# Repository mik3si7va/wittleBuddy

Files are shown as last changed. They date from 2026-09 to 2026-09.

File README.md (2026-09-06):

# Wittle Buddy 🤖

Wittle is a modular 2WD experimental mobile robot built from scratch to learn embedded systems, robotics, sensing, navigation, communications, mapping and autonomous behaviour—with room for a little personality along the way.

The main embedded controller / brain is an **Arduino Mega 2560**, programmed in object-oriented C++ using the Arduino framework and PlatformIO Core. This repository is the starting foundation, and will grow as hardware decisions and experiments become concrete.

## 🎮 First Wireless Drive

On **2026-09-06**, Wittle drove under fully wireless Xbox controller control for the first time. An assembled prototype became a remotely controllable mobile robot. 🤖

**Xbox Controller → Bluetooth → ESP32 → UART → Mega 2560 → Motor Driver → Motors**

### 🎥 [Watch Wittle's first wireless drive](docs/videos/001_mileStone001.mp4)

[**First drive: `001_mileStone001.mp4`**](docs/videos/001_mileStone001.mp4) — the footage lives in this repository; open the link to view or download it.

The **Mega 2560 remains Wittle's brain**: it owns motor control and the final command-timeout failsafe. The ESP32 is the wireless helper, interpreting Bluetooth controller input and sending signed left/right commands over UART. This drive proved the whole chain end-to-end, including both DC motors.

🔋 The wonderfully simple breakthrough for untethered power was a **USB power bank**, keeping the control electronics powered after disconnecting the computer. The motors kept their separate 4.5 V battery pack. This is a temporary prototype solution; see the [power debugging story](#power-debugging-a-small-power-bank-big-moment) and [milestone log](#milestone-log).

The current exp003 source maps the **right analog stick** (`axis_rx` / `axis_ry`), although the milestone description called it the left stick. The documentation follows the checked-in source mapping; see the [ESP32 experiment](experiments/esp32_xbox_controller/README.md#experiment-003-uart-motor-control) and [Mega wiring and failsafes](experiments/motor/README.md).

## Current status

**Body assembled:** the first 2WD chassis is built, with two acrylic decks, two geared DC motors and drive wheels, and two swivel casters. Motor leads have been attached, and the upper deck is in place for mounting electronics. See the [assembly photos](#body-assembly-ass001) below.

**Working on hardware:** Xbox-controlled wireless driving through the ESP32 → UART → Mega → dual motor driver → two DC motors, with portable control power from a USB power bank.

**Implemented:** a PlatformIO Mega firmware target, a lightweight experiment launcher, and a reusable `UltrasonicSensor` class. The active motor experiment (`exp003`) receives signed motor commands from the ESP32 over Serial1 with a 400 ms watchdog. The ultrasonic experiment remains available under `experiments/ultrasonic/`. The five subsystem classes remain skeletons with empty `begin()` and `update()` methods and are not instantiated. There are no automated tests yet.

**Planned:** reusable drive subsystem integration and encoder support, odometry and IMU integration, distance sensing, battery monitoring, communication with higher-level controllers, and a behaviour state machine.

**Experimental / future ideas:** 360-degree LiDAR integration, mapping, autonomous navigation, further ESP32 cooperation and expressive behaviours. These are exploration directions, not working capabilities or settled designs.

## Body assembly (ass001)

Wittle now has an assembled body. Photos 007–011 document the build from the loose chassis parts through motor lead preparation to the assembled base and upper deck.

The two motors and drive wheels are mounted to the lower chassis, with two swivel casters providing support. Standoffs separate the clear acrylic decks, leaving space for electronics. At this assembly stage, controller, motor-driver, sensor and power integration were still ahead. The first powered wireless drive is now recorded above; these photos preserve the earlier assembly milestone.

| Parts laid out | Motor terminal wiring | Motor leads prepared |
| --- | --- | --- |
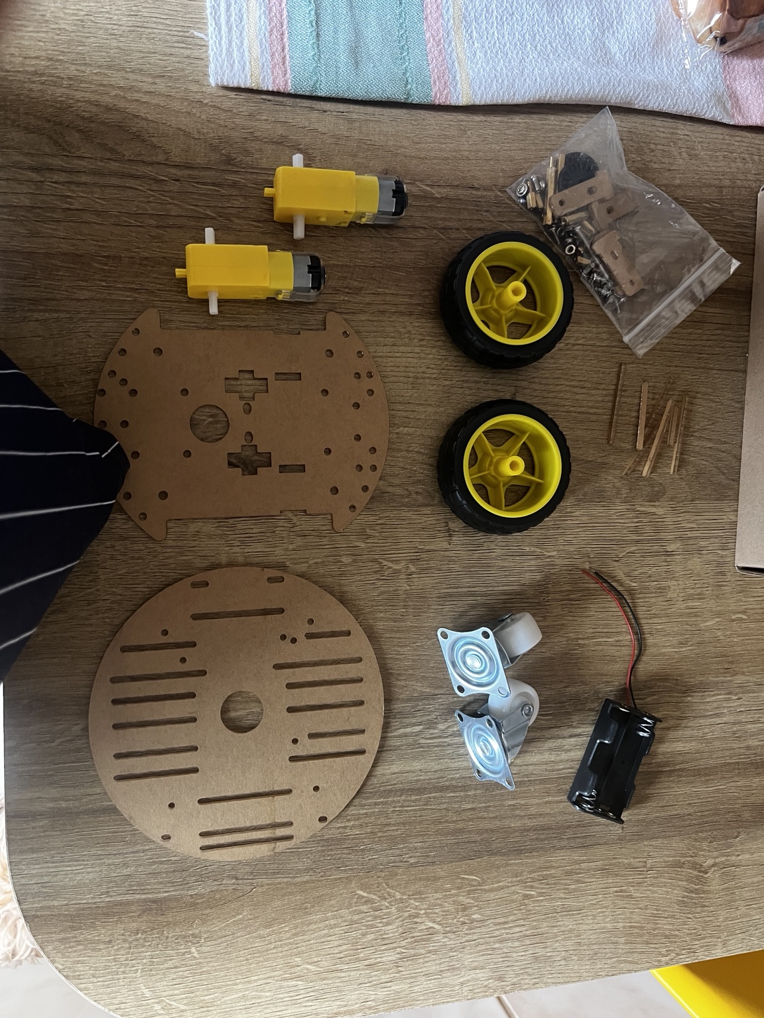
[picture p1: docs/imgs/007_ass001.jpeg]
007: Chassis plates, two motors, wheels, casters and mounting hardware
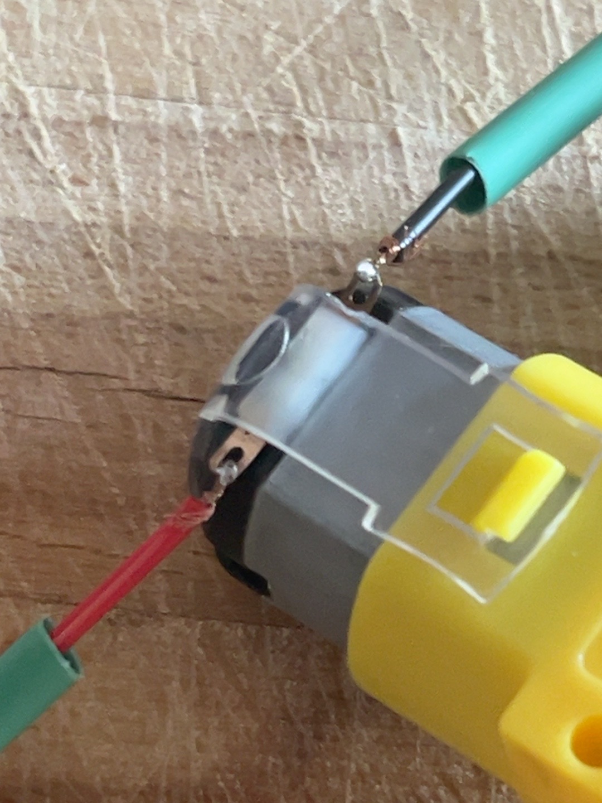
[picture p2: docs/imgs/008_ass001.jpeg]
008: Close-up of motor terminal wiring and insulating sleeves
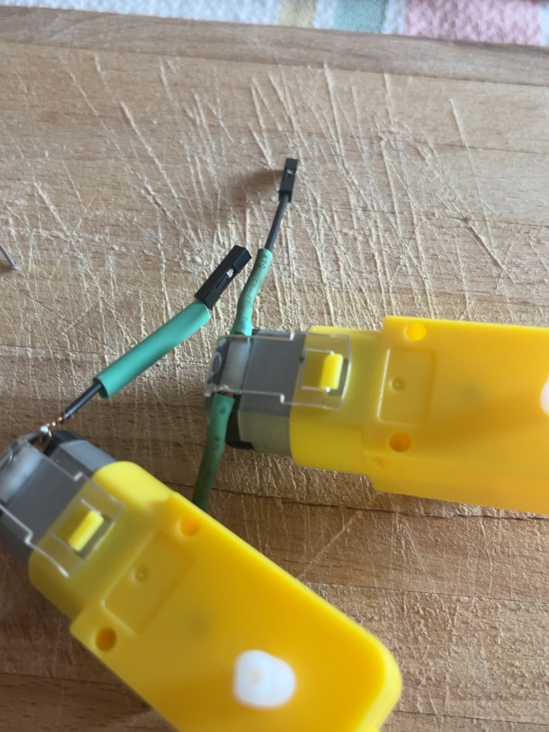
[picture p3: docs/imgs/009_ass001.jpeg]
009: Both geared motors with leads attached
|  |  |  |

| Assembled underside | Upper deck installed |
| --- | --- |
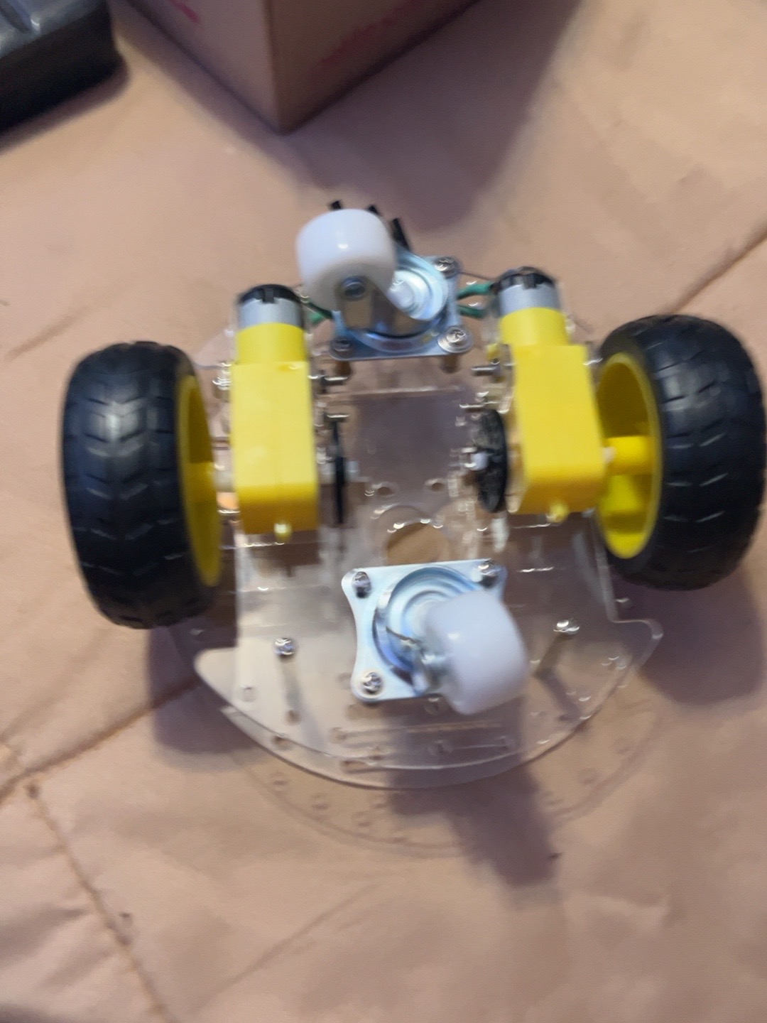
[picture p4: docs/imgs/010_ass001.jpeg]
010: Underside showing the two mounted motors, drive wheels and swivel casters
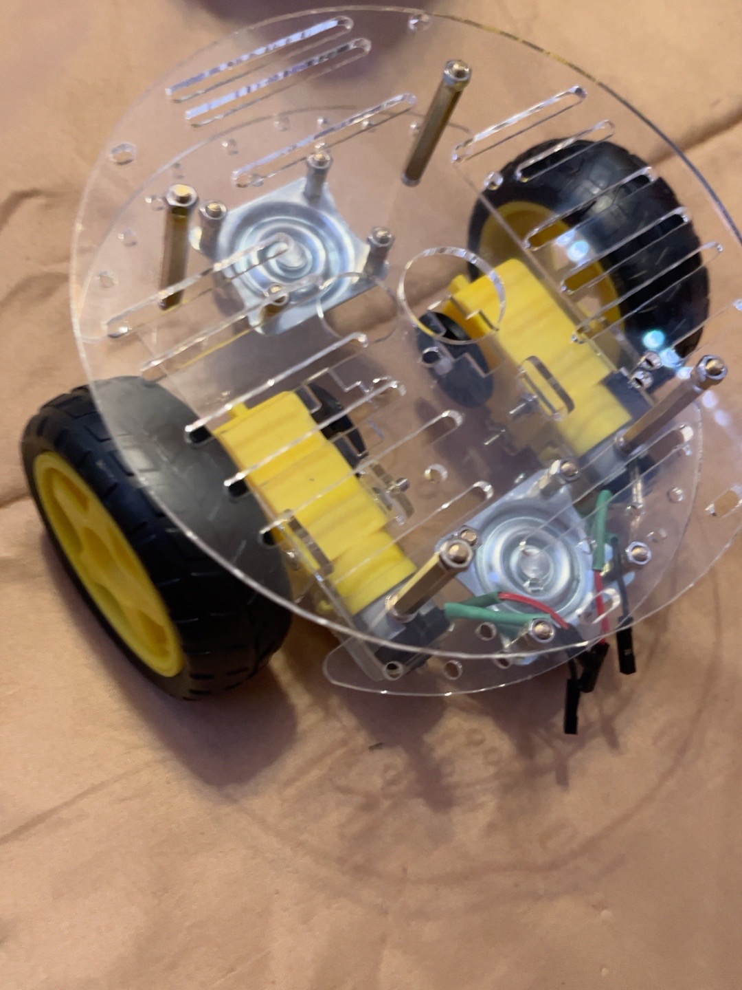
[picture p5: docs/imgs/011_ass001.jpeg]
011: Assembled body with the upper acrylic deck mounted on standoffs
|  |  |

## Architecture

The working exp003 chain is **Xbox controller → Bluetooth → ESP32 → one-way UART → Mega 2560 → GPIO/PWM → dual motor driver → left/right DC motors**. Wireless input belongs to the ESP32; motor actuation and command validation/timeout belong to the Mega. This experiment is working, while the subsystem classes below remain planned integration boundaries.

| System | Planned responsibility |
| --- | --- |
| `DriveSystem` | DC motors and wheel encoders |
| `Navigation` | Odometry, IMU and pose/movement estimation |
| `Perception` | Ultrasonic, ToF and 360-degree LiDAR sensing |
| `PowerSystem` | Battery voltage monitoring and power state |
| `Communication` | Higher-level controllers, telemetry and commands |

`main.cpp` stays small. Future application orchestration and a behaviour state machine will coordinate these systems. The motor and ultrasonic experiments have defined pin assignments; broader robot wiring, protocols and timing contracts remain TBD. See [architecture](docs/architecture.md), [hardware inventory](docs/hardware.md) and [roadmap](docs/roadmap.md).

## Repository structure

```text
wittleBuddy/
├── README.md
├── platformio.ini
├── .vscode/extensions.json       # Optional PlatformIO IDE recommendation
├── docs/
│   ├── architecture.md
│   ├── hardware.md
│   ├── roadmap.md
│   ├── imgs/                     # Assembly and experiment photos
│   └── videos/                   # First wireless drive footage
├── include/                     # UltrasonicSensor.h and subsystem interfaces
├── src/                         # Launcher, UltrasonicSensor.cpp and subsystem skeletons
├── test/                        # Reserved for PlatformIO tests
└── experiments/                 # Implementations; selected experiment is built
    ├── motor/
    ├── esp32_xbox_controller/    # Separate ESP32 PlatformIO project
    ├── encoder/
    ├── ultrasonic/
    ├── tof/
    ├── servo/
    └── lidar/
```

PlatformIO makes `include/` available for headers. The root configuration sets `src_dir = .` and explicitly selects these implementation files with `build_src_filter`:

```ini
build_src_filter =
    +<src/main.cpp>
    +<experiments/motor/exp003.cpp>
```

This compiles the experiment in place, without copying it into `src/` or creating another project or environment. Other experiments and the subsystem skeletons are not compiled.

## Running experiments

`src/main.cpp` owns the Arduino `setup()` and `loop()` functions. It includes the experiment header and delegates to `motorExperimentSetup()` and `motorExperimentLoop()`. The implementation stays in `experiments/motor/exp003.cpp`.

The experiment starts both motors stopped, then receives `left,right` commands over Serial1 at 115200 baud. Positive commands use IN1 LOW / IN2 HIGH; a 400 ms command timeout stops both motors. See the [motor experiment README](experiments/motor/README.md) for wiring and bench-test instructions.

To activate a future experiment, keep its implementation and header under its own `experiments/` directory, update the header and calls in `src/main.cpp`, and replace the experiment path in `build_src_filter`. Explicitly include any reusable implementation files it needs. Keep Arduino entry points in `main.cpp`; no selector or registry is required.

## Development setup

Use Python 3 and [PlatformIO Core](https://docs.platformio.org/en/latest/core/installation/). A user-local installation keeps Python packages separate from Fedora's system Python:

```sh
python3 -m venv "$HOME/.platformio/penv"
"$HOME/.platformio/penv/bin/python" -m pip install platformio
export PATH="$HOME/.platformio/penv/bin:$PATH"
pio --version
```

On the initial development machine, Core is installed at that location, with `pio` and `platformio` links in `~/.local/bin` already on PATH. No system package or permission changes were needed. If another machine lacks Python or venv support, resolve its prerequisites before proceeding; do not run PlatformIO with sudo.

For VS Code, open this repository and optionally install the recommended **PlatformIO IDE** extension (`platformio.platformio-ide`). The CLI works independently in VS Code's terminal. Generated PlatformIO build and editor files are ignored by Git.

The board configuration follows the [PlatformIO Mega 2560 definition](https://docs.platformio.org/en/stable/boards/atmelavr/megaatmega2560.html). The Atmel AVR platform is pinned to version 5.3.0. PlatformIO downloads the compiler and Arduino framework on the first build; the uploader is fetched when needed. These downloads require internet access.

## Build, detect, upload and monitor

Run from the repository root:

```sh
pio run -e mega2560
pio device list
```

On the initial machine, USB ID `2341:0042` identifies the Mega 2560 R3 at `/dev/ttyACM0`. Device names can change after reconnecting; check the list before using the following commands.

**Upload only when you choose to replace the board's current firmware:**

```sh
pio run -e mega2560 -t upload --upload-port /dev/ttyACM0
```

For firmware that uses Serial, monitor output with:

```sh
pio device monitor -e mega2560 --port /dev/ttyACM0 --baud 115200
```

Exit the monitor with Ctrl+C and close it before uploading. The current motor experiment prints received commands and failsafe events over USB Serial at 115200; motor commands arrive separately on Serial1 RX pin 19. The startup message in the historical validation record below belongs to the earlier minimal firmware.

For serial access, inspect `id` and `ls -l /dev/ttyACM0`. On the initial Fedora machine the user is already in `dialout`, and the device is read/write for that group. No extra udev rules were needed for this connected board. Review any future permission change explicitly rather than granting world-writable access.

## Sensor refactor build validation (historical)

The sensor-class refactor passed `pio run -e mega2560`: flash usage was 2,348 / 253,952 bytes and RAM usage was 21 / 8,192 bytes. This verified compilation and linking; no firmware upload was performed during the refactor.

## Initial validation (historical)

On 2026-09-05, `pio run -e mega2560` succeeded on Fedora 44 with PlatformIO Core 6.1.19, Atmel AVR 5.3.0, AVR GCC 7.3.0 and Arduino AVR framework package 5.4.0. Flash usage was 1,856 / 253,952 bytes; RAM usage was 188 / 8,192 bytes. AVRDUDE 6.3 was installed separately through PlatformIO and its help command ran successfully. PlatformIO device enumeration and the monitor CLI were available.

The connected Arduino Mega 2560 at `/dev/ttyACM0` was successfully flashed using AVRDUDE. All 1,856 bytes were written and verified. After reset, serial communication at 115200 baud was verified with the exact startup output:

```text
Wittle Buddy starting up!
```

The received bytes were `b'Wittle Buddy starting up!\r\n'`. This confirms the minimal firmware runs and serial communication works; robot subsystems remain unimplemented. Serial access permissions were checked, and no system packages, group memberships or udev rules were changed.

## Power debugging: a small power bank, big moment

The ESP32 initially ran from the Mega's 5 V rail while the Mega was connected to USB. Removing the computer tether exposed a power problem:

| Attempt | What happened / lesson |
| --- | --- |
| Small rectangular 9 V battery → Mega external input → onboard regulator → Mega 5 V rail → ESP32 | The ESP32/controller setup became unreliable. The likely bottleneck was the small battery plus the Mega regulator supplying the combined Mega + ESP32 wireless load. |
| Motor battery pack (4.5 V) → ESP32 VIN/5V input | Also unsatisfactory. 4.5 V is marginal at the development board's VIN/5V input, and directly sharing motor power introduces voltage-drop and motor-noise concerns. |
| USB power bank → control electronics | Worked: portable regulated USB power kept the Mega/ESP32 system running with the computer disconnected. Motors retained their separate 4.5 V supply through driver VM, with common ground. |

After experimenting with a 9 V battery and the motor supply, the breakthrough power solution for the first untethered test was unexpectedly simple: **a USB power bank**. Sometimes the next robotics breakthrough is already in a drawer. 🔋

The unsuccessful arrangements were abandoned. These observations point to the power architecture; they are not measured regulator or noise diagnoses. The power bank is a **temporary prototype solution**, not a settled final design. A future main rechargeable battery with appropriate DC-DC regulation can supply the robot; that architecture has not been implemented.

## Milestone log

### 2026-09-06 — First wireless drive 🎮📡

1. Soldered the motor-driver header pins, brought the board online and debugged its wiring. Missing **VM motor power** explained why the motors initially would not move.
2. Successfully tested both DC motors. Both initially ran backwards; software direction was corrected and forward was experimentally confirmed as **AIN1/BIN1 LOW, AIN2/BIN2 HIGH**.
3. Connected the Xbox controller to the ESP32 over Bluetooth, implemented/tested ESP32 → Mega UART, and had the Mega translate wireless commands into motor movement.
4. Tried removing the USB tether with a small 9 V battery through the Mega and then the existing 4.5 V motor supply for the ESP32. Neither arrangement reliably powered the wireless setup.
5. Used a USB power bank as temporary portable 5 V control power, keeping the motors on their separate battery supply. Wittle completed its **first fully wireless Xbox-controlled drive**.
6. Recorded the first-drive footage, present here as [001_mileStone001.mp4](docs/videos/001_mileStone001.mp4) (called `Wittle001.mp4` in the session description).

This was the day Wittle moved beyond an assembled prototype and became a remotely controllable mobile robot. Hardware results above are from the reported driving session; implemented failsafes are documented separately from suggested bench checks.

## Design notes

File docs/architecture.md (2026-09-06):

# Software architecture

## Current implementation

The project uses PlatformIO's Arduino framework for the Mega 2560. `src/main.cpp` owns Arduino `setup()` and `loop()` and delegates to the active motor experiment through `experiments/motor/exp003.h`.

The working control chain, proven in the first wireless drive on **2026-09-06**, is Xbox controller → Bluetooth → ESP32 → UART → Mega 2560 → GPIO/PWM → dual motor driver → two DC motors. The **Mega is the main controller / brain** and owns motor control, packet validation and the 400 ms command timeout. The ESP32 is the wireless helper: its separate ESP-IDF/Bluepad32 project mixes right-stick input and sends `left,right\n` commands at 115200 baud every 50 ms. Its 300 ms input timeout is checked on the next timer tick. See the [Mega experiment](../experiments/motor/README.md) and [ESP32 experiment](../experiments/esp32_xbox_controller/README.md#experiment-003-uart-motor-control).

The earlier ultrasonic experiment remains available. It owns three `UltrasonicSensor` objects, compares their distances, and controls traffic-light LEDs. `UltrasonicSensor` stores one TRIG/ECHO pin pair and provides `begin()` and `measureDistance()`; it has no LED or navigation responsibilities. Each subsystem has a header in `include/` and a source in `src/`; `begin()` and `update()` are empty placeholders. No subsystem is instantiated or included in the current build filter.

## Planned boundaries

| Class | Responsibility | Decisions still required |
| --- | --- | --- |
| DriveSystem | Motor actuation and encoder acquisition | Integrate tested motor wiring; encoder format, command and feedback interfaces |
| Navigation | Odometry, IMU integration, pose/movement estimation | IMU, calibration, coordinate frames and data contracts |
| Perception | Ultrasonic, ToF and 360-degree LiDAR sensing | Models, interfaces, sampling and validity representation |
| PowerSystem | Battery voltage and power state | Battery, measurement circuit, thresholds and units |
| Communication | Higher-level controller links, telemetry and commands | Integrate tested ESP32 UART link; broader telemetry and message contracts |

The small lifecycle interface is provisional. Add configuration, results and error reporting only as requirements become known. Empty methods do not indicate functioning or successfully initialized hardware.

## Future orchestration

Keep Arduino `setup()` and `loop()` focused on application orchestration. A future behaviour state machine will select modes and coordinate subsystems through explicit interfaces. States, transitions, command ownership and fault responses are TBD; none are implemented.

Prefer bounded, non-blocking updates as functionality is added. Navigation is expected to consume drive feedback, and behaviours to consume navigation, perception and power information; exact dependencies and scheduling are TBD. Keep sensor/driver details behind the subsystem boundaries and avoid shared mutable globals between systems.

Plan memory use and update timing within the Mega's resource limits. Higher-level processing may eventually move to another controller, but no allocation of mapping or autonomy work is decided.

## Experiments and validation

`experiments/` holds investigations compiled in place when explicitly selected. The root `platformio.ini` uses `src_dir = .` and `build_src_filter` to include only `src/main.cpp` and `experiments/motor/exp003.cpp`. Switching experiments means updating the launcher header/calls and the source filter within the same Mega environment.

Record wiring and reproducible observations in the experiment README. `test/` is reserved for meaningful tests as contracts are defined. The earlier sensor refactor passed compilation and linking without uploading; its experiment uses sensor readings and LED responses with no serial output. See the [ultrasonic experiment](../experiments/ultrasonic/README.md). The active motor experiment prints USB Serial diagnostics and was used in the reported first wireless drive. That result is distinct from exhaustive fault-case validation; suggested bench checks remain in the motor README.

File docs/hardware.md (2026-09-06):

# Hardware inventory

Wittle's intended form is a modular two-wheel-drive robot. The chassis is assembled and the first wireless Xbox-controlled drive succeeded on 2026-09-06. The initial controller choice, USB enumeration, firmware upload and serial startup output have also been confirmed here. Inventory entries below do not imply that components are installed or supported in firmware.

| Item | Status / quantity | Model / specification | Connection / pins | Notes |
| --- | --- | --- | --- | --- |
| Primary controller | Confirmed, 1 detected | Arduino Mega 2560 R3 | USB debug; Serial1 RX19; motor pins below | Initial Arduino framework target |
| USB connection | Upload and serial output verified | USB ID 2341:0042 | `/dev/ttyACM0` during validation | AVRDUDE wrote and verified 1,856 bytes; startup message received at 115200 baud after reset |
| Chassis / wheels | Assembled 2WD | Two acrylic decks, drive wheels and two swivel casters | Two geared motors on lower chassis | Dimensions and wheel geometry TBD |
| DC motors | Both tested, 2 | Geared DC motors; ratings/gearing TBD | Left: AO1/AO2; right: BO1/BO2 | Forward orientation confirmed experimentally |
| Motor driver | Dual driver tested | Exact model not recorded here | PWMA=5, AIN1=22, AIN2=23, STBY=24, BIN1=25, BIN2=26, PWMB=6 | VCC=Mega 5 V; VM=separate 4.5 V pack; common GND |
| Wheel encoders | Planned, quantity TBD | TBD | TBD | Resolution and electrical interface TBD |
| IMU | Planned | TBD | TBD | Calibration and mounting TBD |
| Ultrasonic sensors | Planned, quantity TBD | TBD | TBD | Placement TBD |
| ToF sensors | Planned, quantity TBD | TBD | TBD | Placement TBD |
| 360-degree LiDAR | Future exploration | TBD | TBD | Power and processing needs TBD |
| Motor battery | Tested | 4.5 V pack, 3 × 1.5 V cells | Positive to VM; negative to common GND | Chemistry/capacity not recorded; final rechargeable system planned |
| Voltage measurement | Planned | TBD | TBD | Circuit and scaling TBD |
| Control power | Temporary prototype, tested | USB power bank | Portable USB power for Mega/ESP32 controls | Final DC-DC regulation, protection and current budget TBD |
| Wireless helper | Tested with Xbox over Bluetooth | ESP32 project targets ESP32-WROOM / DOIT ESP32 DEVKIT V1 | GPIO17 UART2 TX → Mega RX1 pin 19; common GND; 115200 baud | Mega remains main controller; one-way motor-command link |
| Servo | Experiment placeholder only | TBD | TBD | No robot role assigned |

## Assignment policy

Confirmed motor wiring and software orientation are recorded in the [motor experiment](../experiments/motor/README.md): forward is AIN1/BIN1 LOW and AIN2/BIN2 HIGH. The earlier [ultrasonic experiment](../experiments/ultrasonic/README.md) has its own conflicting pin assignments; disconnect that wiring before using exp003. Broader robot wiring and sensor addresses remain open. Subsystem classes remain empty, while experiment motor and ultrasonic code performs real operations.

The small 9 V battery through the Mega regulator and the shared 4.5 V motor-supply attempt did not reliably power the ESP32/controller setup. Both were abandoned in favour of temporary USB power-bank control power. See the [power debugging story](../README.md#power-debugging-a-small-power-bank-big-moment); a final rechargeable battery/DC-DC architecture is still future work.

## Development host observation

Initial inspection: Fedora Linux 44, user already in `dialout`; `/dev/ttyACM0` is owned by `root:dialout` with mode `0660`, and the current user has read/write access. No permissions or udev rules were changed. Device paths and access must be rechecked on another host or after reconnecting.

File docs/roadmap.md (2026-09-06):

# Roadmap

This is a sequence of learning milestones, not a delivery schedule. Hardware and interface choices remain open.

## Foundation — implemented

- PlatformIO configuration for Mega 2560 and Arduino.
- Minimal serial startup firmware.
- Five subsystem class skeletons, documentation and experiment directories.

## Toolchain bring-up — validation

- Completed: firmware compiles on Fedora; memory usage and tool versions are recorded in the README.
- Completed: Mega detected at `/dev/ttyACM0`; current user has read/write access.
- Completed: AVRDUDE uploaded and verified all 1,856 bytes on the Mega at `/dev/ttyACM0`; after reset, `Wittle Buddy starting up!` was received at 115200 baud.

## First wireless drive — completed, 2026-09-06

- Soldered and debugged motor-driver wiring, identified missing VM power, tested both motors and corrected forward direction in software.
- Proved Xbox → Bluetooth → ESP32 → UART → Mega → motor driver → motors end-to-end.
- Replaced inadequate prototype power attempts with temporary USB power-bank control power and a separate 4.5 V motor pack.
- Recorded [the first wireless drive](videos/001_mileStone001.mp4). See the [full milestone log](../README.md#milestone-log).

## Hardware decisions and isolated experiments — ongoing

- Inventory available components and confirm motor, driver and power requirements.
- Extend confirmed motor/UART and earlier ultrasonic pin assignments as further electrical and timing requirements are checked.
- Investigate motors, encoders, ultrasonic, ToF, servo and LiDAR independently where relevant.
- Record measurements and findings before integrating code.

## Subsystem integration — planned

- Integrate working experiment motor control into DriveSystem and add encoder feedback, followed by odometry and IMU integration.
- Add perception and power monitoring using confirmed hardware.
- Integrate the working ESP32 UART controller link into subsystem communication contracts.
- Develop the final rechargeable battery and appropriate DC-DC regulation beyond temporary power-bank control power.
- Add tests for established logic and repeatable hardware checks for drivers.

## Behaviour coordination — planned

- Define a behaviour state machine, transitions, fault handling and update timing.
- Integrate subsystems incrementally with measurable acceptance criteria.

## Exploration — future ideas

Mapping, autonomous navigation, 360-degree LiDAR processing, further ESP32 cooperation and expressive behaviour remain future investigations. Feasibility and division of work between controllers need experimental evidence.

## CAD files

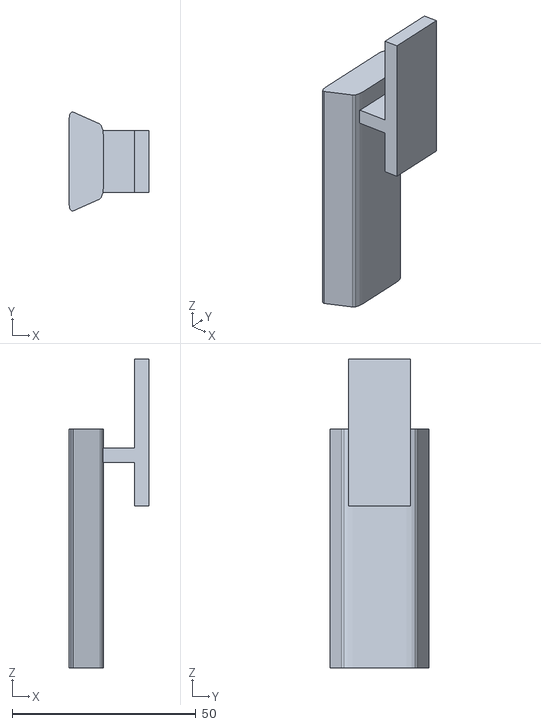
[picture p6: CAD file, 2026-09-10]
blender/stl/v001 (plain)/005_clip.stl
21.7 x 26.9 x 84.1

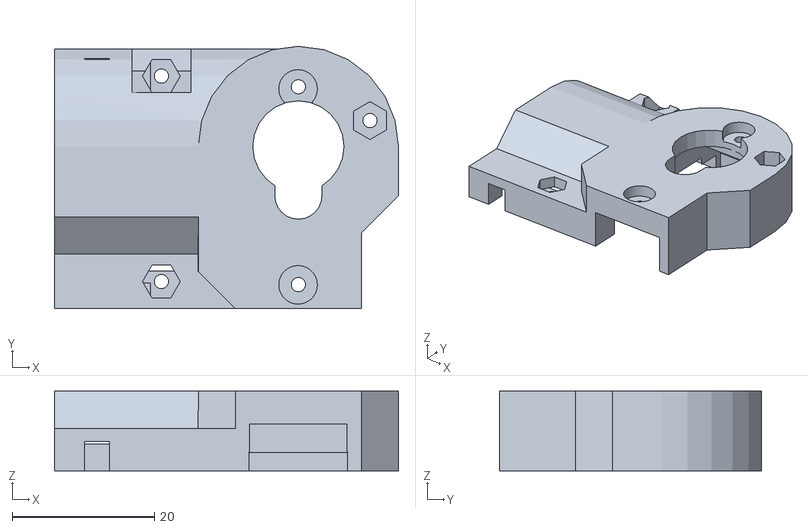
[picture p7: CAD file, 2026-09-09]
blender/stl/v002 (camara)/001_raspicam_pan_tilt_for_mg90s_servos_from_cults3d/PanTilt_Body-A.stl
48.3 x 36.8 x 11.2

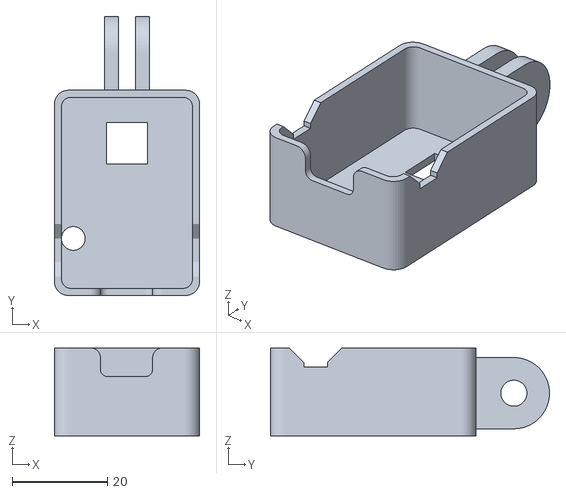
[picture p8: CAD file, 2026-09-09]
blender/stl/v002 (camara)/002_esp32_cam_holder_from_cults3d/ESP32-CAM-Front-Gopro-MB.stl
30.6 x 58.7 x 18.5

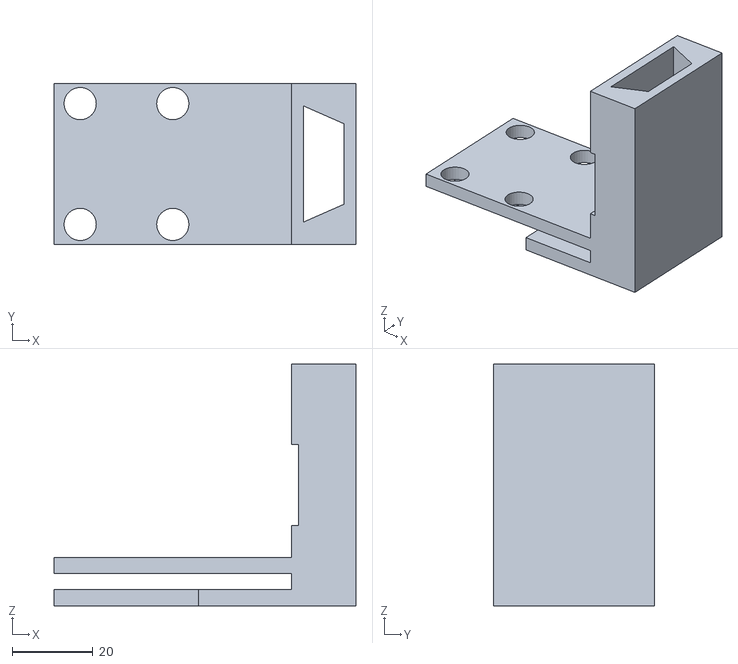
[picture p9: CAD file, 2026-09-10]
blender/stl/v001 (plain)/004_Bp_clamp.stl
75.0 x 40.0 x 60.0

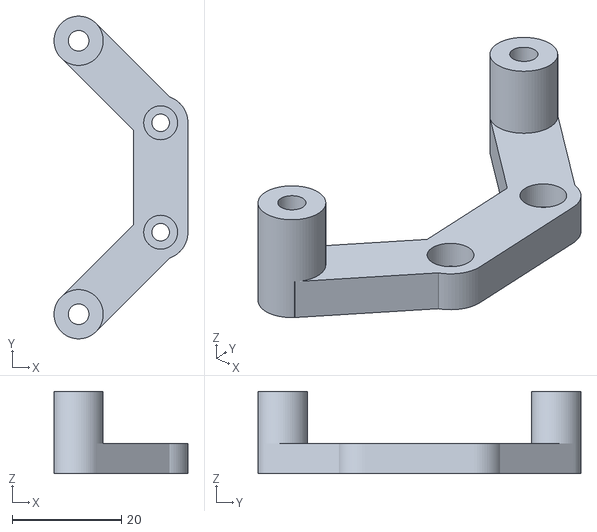
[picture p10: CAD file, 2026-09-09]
blender/stl/v002 (camara)/001_raspicam_pan_tilt_for_mg90s_servos_from_cults3d/PanTilt_Feet_print_x2.stl
24.5 x 59.0 x 15.0

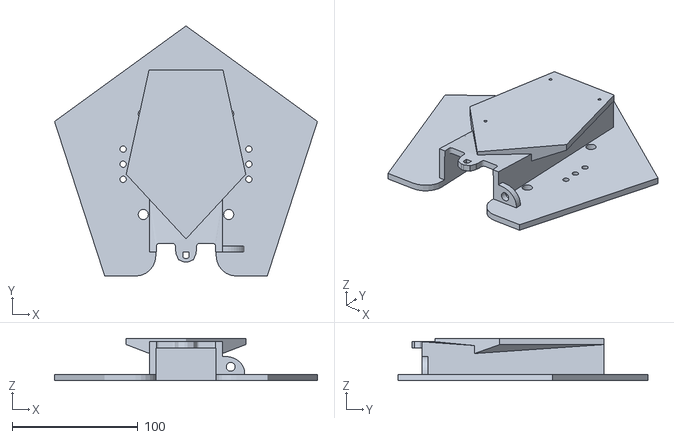
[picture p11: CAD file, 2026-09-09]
blender/stl/v001 (plain)/001_body_v1.stl
209.2 x 199.0 x 33.8

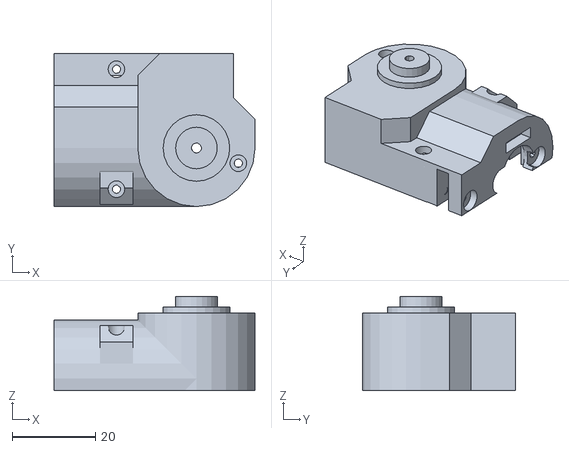
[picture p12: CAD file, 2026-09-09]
blender/stl/v002 (camara)/001_raspicam_pan_tilt_for_mg90s_servos_from_cults3d/PanTilt_Body-B.stl
48.3 x 36.8 x 22.6

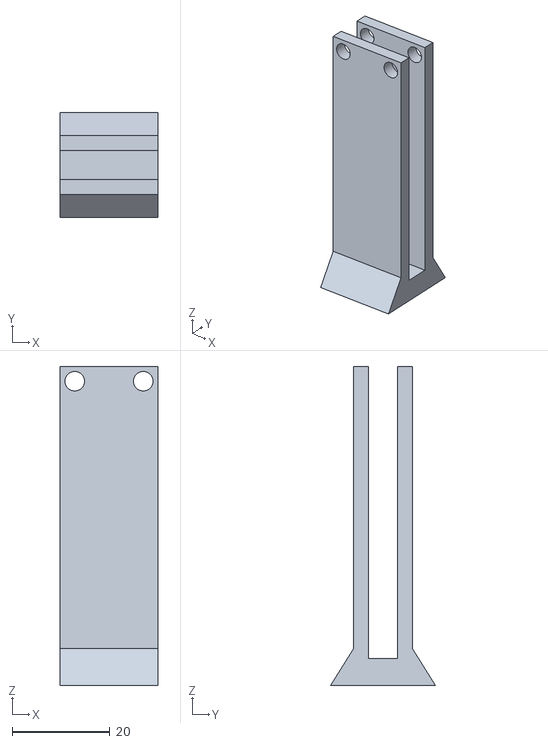
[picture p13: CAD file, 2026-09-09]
blender/stl/v001 (plain)/006_esp_stand.stl
20.0 x 21.5 x 65.2

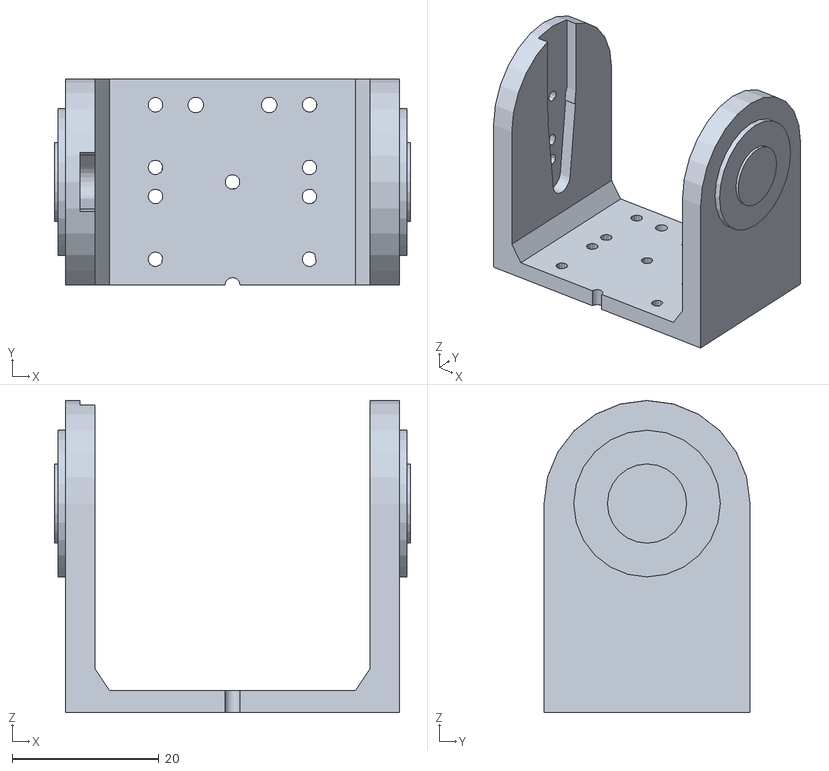
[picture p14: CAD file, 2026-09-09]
blender/stl/v002 (camara)/001_raspicam_pan_tilt_for_mg90s_servos_from_cults3d/PanTilt_Arm.stl
48.5 x 28.1 x 42.5

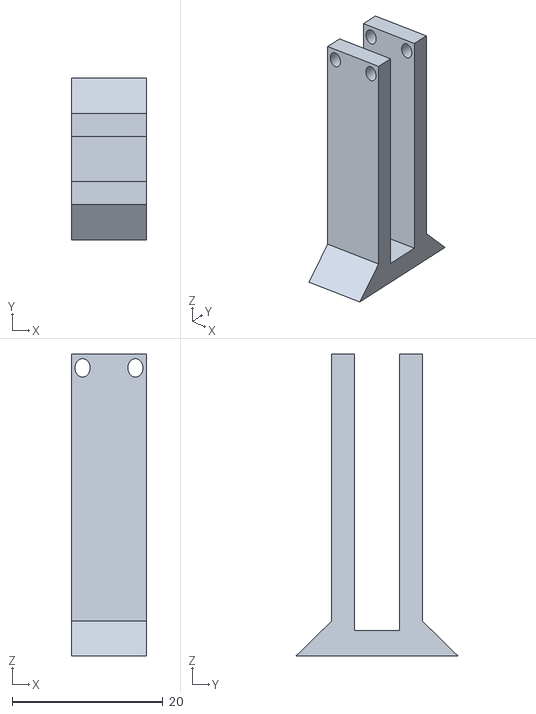
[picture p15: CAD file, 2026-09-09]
blender/stl/v001 (plain)/007_m_driver_stand.stl
10.0 x 21.5 x 40.0

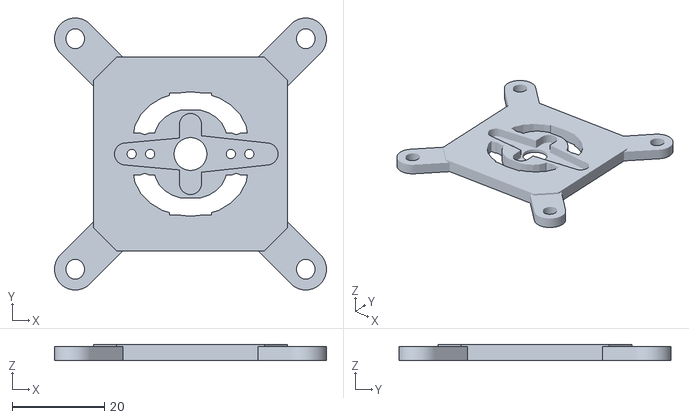
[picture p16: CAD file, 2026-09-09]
blender/stl/v002 (camara)/001_raspicam_pan_tilt_for_mg90s_servos_from_cults3d/PanTilt_Base.stl
59.0 x 59.0 x 3.50

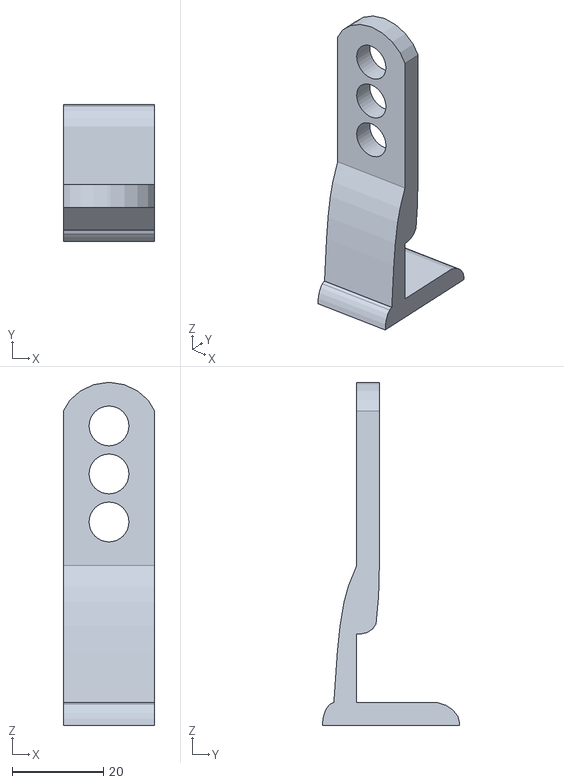
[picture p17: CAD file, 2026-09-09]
blender/stl/v001 (plain)/008_traffic_light_holder.stl
20.0 x 30.0 x 75.0

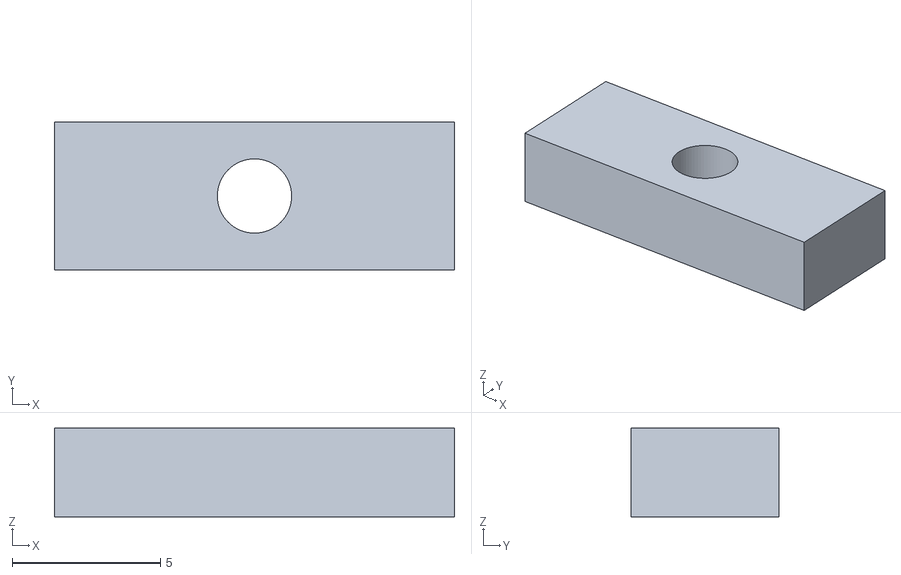
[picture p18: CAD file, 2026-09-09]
blender/stl/v002 (camara)/001_raspicam_pan_tilt_for_mg90s_servos_from_cults3d/PanTilt_Block.stl
13.5 x 5.00 x 3.00

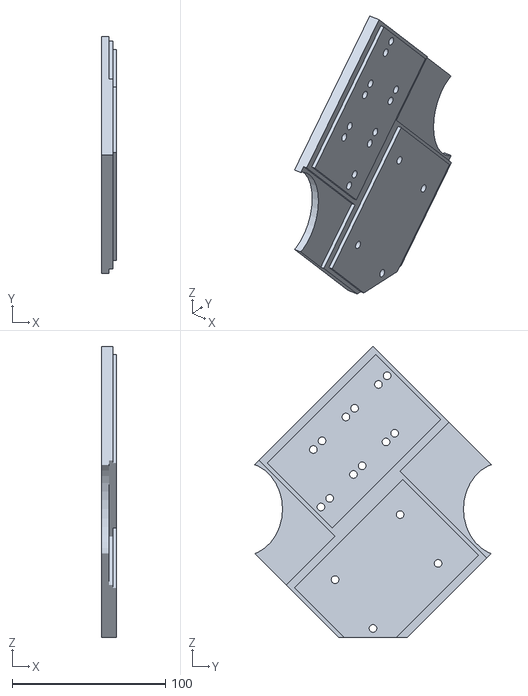
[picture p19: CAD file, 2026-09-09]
blender/stl/v001 (plain)/003_backPlate_v01.stl
10.0 x 154.3 x 189.7

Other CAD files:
blender/stl/v002 (camara)/001_raspicam_pan_tilt_for_mg90s_servos_from_cults3d/PanTilt_Baselock.stl
blender/stl/v001 (plain)/002_body_key_v01.stl
blender/blend/v001/back_plate_v1.blend
blender/blend/v001/body_v1.blend
blender/blend/v001/esp_plus_driver_stand_v1.blend
blender/blend/v001/traffic_light_v1.blend

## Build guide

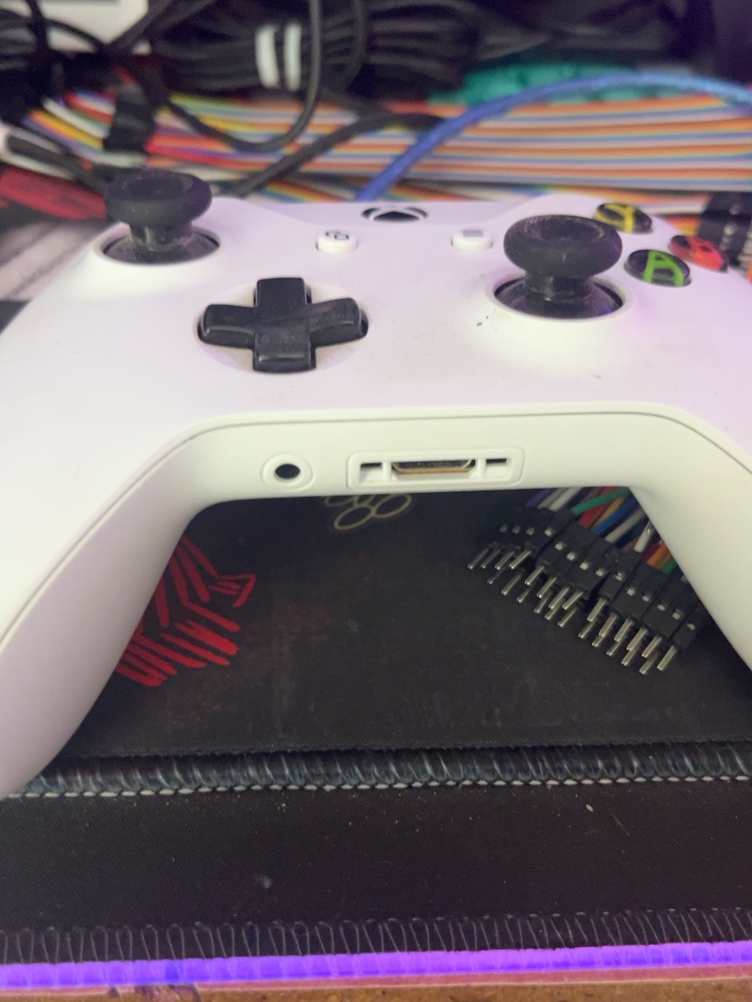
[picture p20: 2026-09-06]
docs/imgs/001_baby_steps/018_exp003.jpeg

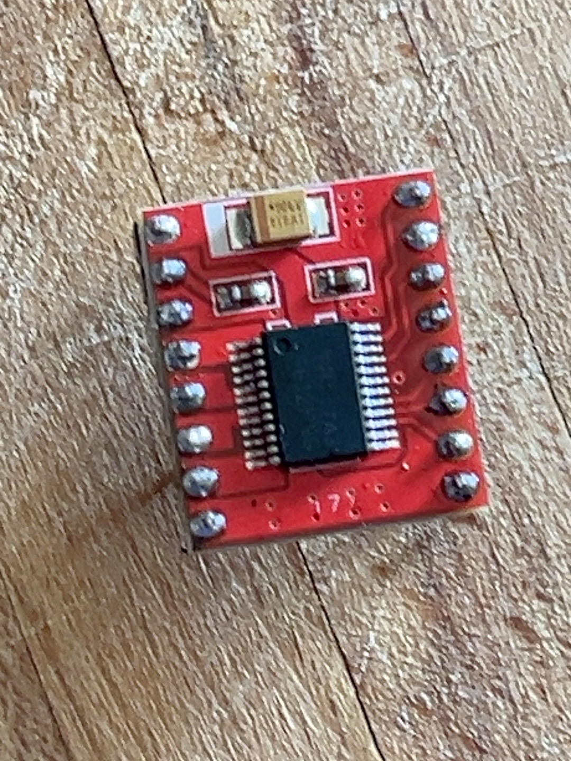
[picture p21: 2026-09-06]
docs/imgs/001_baby_steps/015_exp003.jpeg

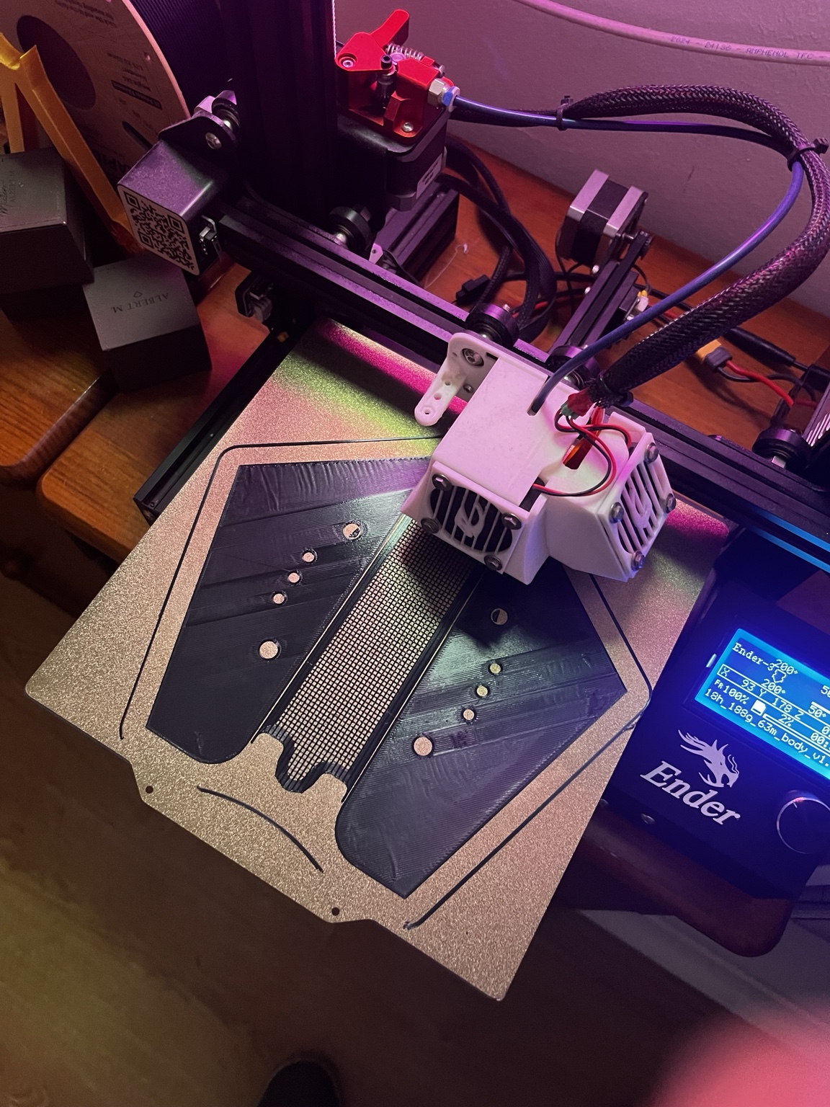
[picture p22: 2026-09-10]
docs/imgs/002_first_prototype/008_printing.jpeg

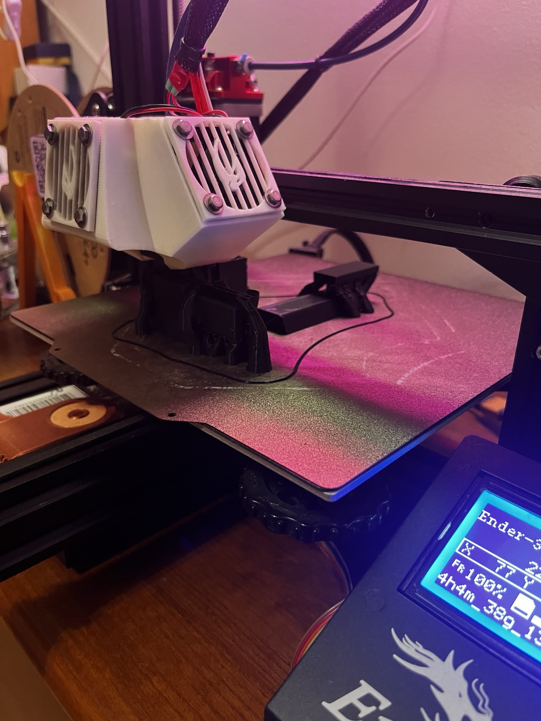
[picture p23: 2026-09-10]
docs/imgs/002_first_prototype/009_more_printing.jpeg

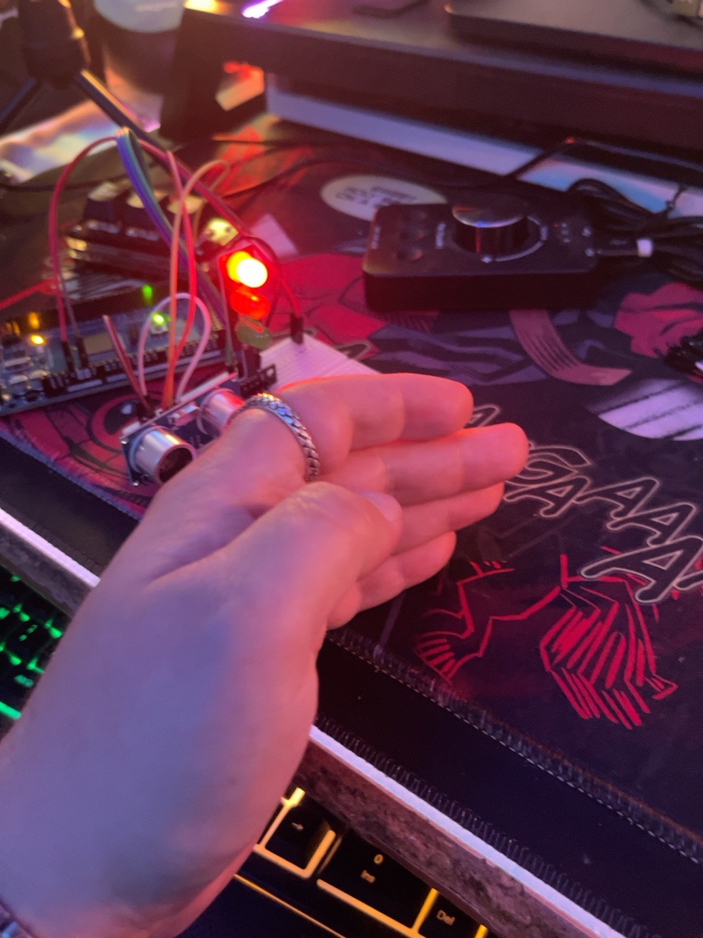
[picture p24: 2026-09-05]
docs/imgs/001_baby_steps/001_exp001.jpeg

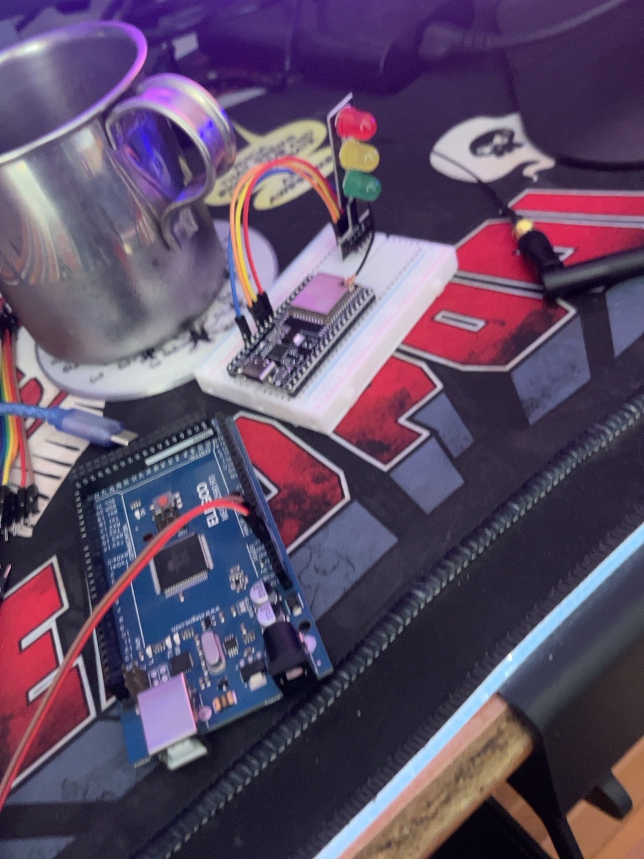
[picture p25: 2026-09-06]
docs/imgs/001_baby_steps/017_exp003.jpeg

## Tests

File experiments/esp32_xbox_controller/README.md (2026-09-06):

# ESP32 Xbox controller experiments

Standalone PlatformIO project for the **original ESP32-WROOM / DOIT ESP32 DEVKIT V1** (4 MB flash). The root Mega build, production sources, and ultrasonic experiments are independent and unchanged. Open this directory as the PlatformIO project, or use the commands below.

**Milestone — 2026-09-06:** exp003 supplied the wireless input for [Wittle's first wireless drive](../../docs/videos/001_mileStone001.mp4). The ESP32 is the Bluetooth/UART helper; the Mega remains the brain and controls the motors. See [Experiment 003](#experiment-003-uart-motor-control) for its explicit build commands. The setup, LED mapping and validation below describe the original traffic-light experiment (`esp32_xbox`, still the default environment).

## Build and upload

### VS Code IntelliSense

Open `esp32_xbox.code-workspace` using **File > Open Workspace from File**.
This makes the experiment the editor's PlatformIO project. Opening only the
repository root uses the Mega/AVR IntelliSense configuration, which can flag
ESP32 and even standard C++ headers as missing despite a successful ESP32 build.
PlatformIO supports [project-specific VS Code workspaces](https://docs.platformio.org/en/latest/integration/ide/vscode.html).

To regenerate local editor metadata from this directory:

```sh
pio project init --ide vscode
```

If squiggles persist in the experiment workspace, run **PlatformIO: Rebuild
IntelliSense Index** from the Command Palette, then **Developer: Reload Window**.
Generated `.vscode/c_cpp_properties.json` contains local compiler/include paths
and is ignored by Git. No firmware source or compiler flags need changing.

### Commands

Prerequisites: PlatformIO Core (`pio`), Git, Python 3, and internet access for the first build. PlatformIO installs the ESP-IDF toolchain; no Arduino IDE or Arduino Bluepad32 board package is used.

From the repository root:

```sh
cd experiments/esp32_xbox_controller
pio run
pio run -t upload
pio device monitor -b 115200
```

Or upload directly from the repository root:

```sh
pio run -d experiments/esp32_xbox_controller -t upload
```

`upload_port` and `monitor_port` are both `/dev/ttyUSB0`. Change them in this project's `platformio.ini` if Linux assigns another port (`pio device list` lists ports). Close other serial monitors before uploading. If upload stays at `Connecting...`, hold BOOT while connecting, then release when writing begins. On Fedora, a permission-denied error means your user needs access to the serial device; inspect its ownership and your group membership. Exit the monitor with Ctrl+C. Press EN/reset after opening the monitor to see boot diagnostics.

Upload troubleshooting: `upload_speed = 115200` avoids switching to the board's
default 460800 baud transfer rate. If the stub starts but upload then reports
`Unable to verify flash chip connection (No serial data received)`, retry at this
speed. If it still fails, unplug/reconnect USB, try a known-good data cable and a
direct USB port, and retry with the LED module disconnected. An implausible
crystal-frequency warning during upload does not establish the actual crystal
frequency; do not change the firmware clock configuration based on that warning
alone. See [Espressif's upload troubleshooting](https://docs.espressif.com/projects/esptool/en/release-v4/esp32/troubleshooting.html).

## Wiring and mapping

Disconnect power while wiring. Use the traffic-light module's existing current limiting and 3.3 V compatible inputs; ESP32 GPIOs are not 5 V tolerant. Outputs are active HIGH, matching the existing module convention.

| Module connection | ESP32 connection | Controller mapping |
| --- | --- | --- |
| RED | GPIO 25 | B |
| YELLOW | GPIO 26 | X |
| GREEN | GPIO 27 | A |
| GND | GND | Common ground |

Y turns all three LEDs on. Simultaneous A/B/X presses light their corresponding LEDs together. Releasing all mapped face buttons turns everything off. Boot and active-controller disconnection also turn all LEDs off. Other inputs do not affect LEDs. The first ready gamepad becomes active; additional controllers are rejected until it disconnects.

## Pair and observe

1. Upload, open the monitor at 115200, and reset the ESP32 if necessary.
2. Look for `[BOOT]`, `[BLUEPAD32] Initialized`, and `[WAITING]`.
3. Turn on the Xbox controller and hold its pairing button until the Xbox light flashes rapidly. Disconnect it from another nearby host if that host reconnects automatically.
4. Look for `[DISCOVERED]`, then `[CONNECTED]` and `[READY]`. Copy the **controller Bluetooth address** from `[READY]`. Discovery names can be unavailable; a bonded reconnect may not produce a discovery callback.
5. Press buttons and move sticks/triggers. `[INPUT] First controller input received` confirms actual reports. `[BUTTONS]` prints face-button and D-pad changes, including releases. `[INPUT]` snapshots show A/B/X/Y, decoded D-pad, LX/LY, RX/RY, LT and RT.
6. Check A=green, B=red, X=yellow, Y=all, releases=off. Power off the controller and check `[DISCONNECTED]` and LEDs off once the Bluetooth stack detects the disconnect.

Stick values are Bluepad32's normalized values (nominally -512 to 511); LT=`brake` and RT=`throttle` are nominally 0 to 1023. Analog snapshots are limited to 10 Hz and may skip intermediate samples; digital changes are logged separately. LED updates happen on every gamepad report. BTstack timers provide the waiting heartbeat and snapshots without `delay()` or sleeps in controller callbacks. These are bench diagnostics, not a lossless input recorder.

Use a Bluetooth-capable Xbox Wireless Controller. Upstream documents models 1708 and 1914 and their supported firmware; older Xbox controllers without Bluetooth cannot pair this way. Both Bluetooth Classic and BLE are enabled for Xbox firmware variants. See [Bluepad32's supported Xbox controllers](https://github.com/ricardoquesada/bluepad32/blob/e9b755faabc240585da42e6d26164bb2cdd064d3/docs/supported_gamepads.md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).

If boot appears but initialization does not, capture the intervening stack logs. If waiting repeats without discovery, check pairing mode, controller model, power, and other hosts. If connected appears without ready/input, capture the HID/parser logs and controller firmware version. Pairing keys persist normally. For stale bonds only, temporarily set `kForgetPairingKeysOnBoot = true` in `src/main.cpp`, upload and reboot, then restore `false` and upload again before pairing normally.

## Optional controller identity restriction

Initially `kAllowedControllerAddress` in `src/main.cpp` is empty: no Xbox MAC is hard-coded and normal pairing is allowed. The experiment explicitly disables any previously persisted allowlist when this constant is empty.

After pairing successfully, verify the address printed at `[READY]` stays the same through controller power cycles and ESP32 reboots. Then, optionally, put that exact colon-separated address in `kAllowedControllerAddress`, rebuild and upload. The code uses the verified APIs `uni_bt_allowlist_remove_all()`, `uni_bt_allowlist_add_addr()` and `uni_bt_allowlist_set_enabled()` during `on_init_complete`, before scanning starts. A malformed/zero address or insertion failure leaves acceptance disabled and prints an error. Bluepad32 stores the allowlist in NVS; this experiment replaces it when a nonempty constant is configured. Set the constant back to empty and upload to disable filtering again.

The printed value is `uni_hid_device_t::conn.btaddr`, the remote Bluetooth address exposed by the pinned library. Upstream checks its allowlist during discovery and incoming Classic connections. Address filtering is only useful if this controller/firmware presents a stable address; it is not cryptographic identity verification. A BLE address that changes, or an address changed by firmware/reset, can prevent reconnection. Leave filtering off until stability is confirmed on the actual controller.

## Dependencies and files

This uses the [official Bluepad32 ESP32 raw API example](https://github.com/ricardoquesada/bluepad32/tree/e9b755faabc240585da42e6d26164bb2cdd064d3/examples/esp32), adapted to C++ and a standalone PlatformIO project. That pinned example specifies ESP-IDF 5.3. Dependencies are pinned rather than following a moving development branch:

- PlatformIO `espressif32@6.9.0`, ESP-IDF 5.3.1, board `esp32doit-devkit-v1`.
- Bluepad32 4.2.0, commit `e9b755faabc240585da42e6d26164bb2cdd064d3`.
- BTstack submodule commit `5d4d8cc7b1d35a90bbd6d5ffd2d3050b2bfc861c`.

`prepare_bluepad32.py` downloads the pinned source into local ignored `.pio/bluepad32` and runs upstream's BTstack integration script there. No global ESP-IDF installation is patched. First build downloads can take several minutes; subsequent builds reuse the cache. Deleting this project's `.pio` directory causes dependencies to be fetched again.

| File | Purpose |
| --- | --- |
| `platformio.ini` | Separate ESP32 environment and serial ports |
| `esp32_xbox.code-workspace` | Opens the experiment with its own ESP32 editor configuration |
| `src/main.cpp` | Bluepad32 callbacks, diagnostics and LED mapping |
| `src/exp003.cpp` | Right-stick differential mixing, UART motor commands and input timeout |
| `CMakeLists.txt` | ESP-IDF project and dependency component paths |
| `src/CMakeLists.txt` | Registers the C++ application component |
| `prepare_bluepad32.py` | Reproducible source download and BTstack integration |
| `sdkconfig.defaults` | Classic/BLE, UART and custom Bluepad32 platform configuration |
| `dependencies.lock` | Generated ESP-IDF component version lock |
| `partitions.csv` | 3 MB app partition in 4 MB flash, NVS and core-dump space |
| `.gitignore` | Excludes generated SDK configuration and dependency/build cache |
| `README.md` | Setup, pairing, identity and verification instructions |

## Validation

`pio run -d experiments/esp32_xbox_controller` passed with PlatformIO Core 6.1.19:
83,284 bytes RAM (25.4%) and 679,766 bytes flash (21.6% of the 3 MB app partition).
The build produced `.pio/build/esp32_xbox/firmware.bin`. Upstream code emits
unused-console-function and legacy-timer deprecation warnings; no compile or link errors remain.

Hardware session notes (user-tested):

- Upload succeeded after lowering the upload speed from 460800 to 115200.
- The Trust controller connected but timed out during SDP/HID setup; compatibility remains unresolved.
- After switching to the original Xbox controller, the user reported a successful test; Serial showed button and stick input.
- Missing-header squiggles came from the root Mega/AVR editor configuration. Generated ESP32 IntelliSense metadata and added a dedicated workspace; firmware code stayed unchanged.

Physical testing was performed by the user, not the coding agent. Long-term connection stability and optional address filtering have not been verified.

## Experiment 003: UART motor control

`src/exp003.cpp` reuses the working Bluepad32 platform callbacks, discovery,
allowlist handling and pairing-key policy from `src/main.cpp`. The original
traffic-light source and `esp32_xbox` environment remain available. Select the
new `esp32_xbox_exp003` environment to build the motor sender with ESP-IDF.
The existing configuration has an empty controller allowlist address and keeps
pairing keys on boot; exp003 preserves those settings.

**Source/session discrepancy:** the session description says left stick; [the current source](src/exp003.cpp) reads `axis_rx` and `axis_ry`, so exp003 uses the **right stick**. Buttons, triggers and the left stick do not control motors here; exp003 does not drive the traffic-light LEDs.

Right-stick RX/RY use a 50-count per-axis deadzone, rescaled to full range.
Forward is negative RY, and right turn is positive RX. Mixing is
`left = forward + turn`, `right = forward - turn`; both outputs are scaled
proportionally when either exceeds 255. Axis values outside -512..512 cause stop; +512 is clamped to +511. After the inclusive ±50 deadzone, each axis is rescaled using its negative/positive full-scale limit (512/511) with integer arithmetic. No ESP32 motor-driver pins are used.

Connect GPIO17 TX2 to Mega RX1 pin 19 and share ground. UART2 is 115200 8N1,
TX only; leave Mega TX1 disconnected. Packets are ASCII `left,right\n`, with
signed integer values -255..255. Positive is forward; zero is stop.
Startup and controller-ready events send `0,0`; the first ready gamepad is active and additional controllers are rejected until it disconnects. The 50 ms timer keeps sending zero while waiting/disconnected. There is no separate arming button.
Commands repeat every 50 ms. Detected disconnect or unusable reports send `0,0`
immediately; absence of fresh input for 300 ms stops at the next 50 ms tick.
Some controllers may suppress unchanged reports: this deliberately stops on
stale input rather than assuming that a held command remains usable.
USB diagnostics show connection/input state, raw right-stick axes, motor values
and the transmitted packet every 500 ms (`[STATE]`), plus `[BOOT]`, Bluetooth connection events and `[STOP]` reasons. Raw axes retain their last values after stopping; `usable` and transmitted motor values indicate the stop. The Mega independently validates packets and stops after 400 ms without valid commands.

For exp003 pairing-key recovery or optional address restriction, edit the constants in `src/exp003.cpp`; the earlier instructions referencing `src/main.cpp` apply to the LED environment.

The reported first drive proved the complete wireless chain with USB power-bank control power and a separate 4.5 V motor supply. It does not constitute exhaustive disconnect/timeout testing. See the [power lessons](../../README.md#power-debugging-a-small-power-bank-big-moment).

From the repository root:

```bash
pio device list
pio run -d experiments/esp32_xbox_controller -e esp32_xbox_exp003
pio run -d experiments/esp32_xbox_controller -e esp32_xbox_exp003 -t upload --upload-port /dev/ttyUSB0
pio device monitor -d experiments/esp32_xbox_controller -e esp32_xbox_exp003 --port /dev/ttyUSB0 --baud 115200
```

Replace `/dev/ttyUSB0` with the actual ESP32 USB port. Close monitors before
uploading; Ctrl+C exits. The Mega has its own separate root PlatformIO build;
see the [motor experiment](../motor/README.md). Keep wheels raised during tests.

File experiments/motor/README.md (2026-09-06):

# Motor experiments

## exp003: Xbox to ESP32 to Mega UART motor control

**2026-09-06: first successful wireless drive.** The complete controller → Bluetooth → ESP32 → UART → Mega → motor driver → motors chain worked on hardware. [Watch the first drive](../../docs/videos/001_mileStone001.mp4); see the [milestone and power story](../../README.md#milestone-log). The Mega remains the main controller and owns motor actuation and its receive failsafe.

`src/main.cpp` delegates to the existing `exp003.cpp`. Motor A is the left
channel and Motor B is the right channel. Positive speeds use IN1 LOW / IN2 HIGH
for both motors; negative speeds reverse those levels. Zero disables PWM.
Startup holds STBY LOW while configuring outputs, stops both motors, then enables STBY.

Both motors initially ran backwards in physical testing. The experimentally confirmed **forward** orientation is AIN1 LOW / AIN2 HIGH for Motor A and BIN1 LOW / BIN2 HIGH for Motor B. PWM is removed before setting direction and then set to the command magnitude. A zero command sets both direction pins LOW and PWM to zero; stopping does not lower STBY.

| Driver pin | Mega pin / connection |
| --- | --- |
| PWMA | 5 |
| AIN1 | 22 |
| AIN2 | 23 |
| STBY | 24 |
| BIN1 | 25 |
| BIN2 | 26 |
| PWMB | 6 |
| VCC | Mega 5V |
| GND | Mega GND and motor supply negative |
| VM | 4.5 V battery pack positive (3 × 1.5 V cells), tested supply |
| AO1 / AO2 | Left motor |
| BO1 / BO2 | Right motor |

ESP32 GPIO17 TX2 connects to Mega pin 19 RX1. Connect ESP32 GND, Mega GND,
driver GND and motor-supply negative together. Leave Mega TX1 disconnected.
Disconnect the previous ultrasonic wiring from pins 22–26.

UART uses 115200 baud, 8N1, one-way ASCII `left,right\n`, each value -255..255.
Malformed, overlong, non-ASCII and out-of-range packets stop the motors and do
not refresh the watchdog. Rejection happens when the terminating newline arrives; an incomplete or discarded line without a newline leaves the 400 ms watchdog to stop an active command. The buffer holds at most 15 characters before the terminator, and each loop reads at most 32 bytes so incoming garbage cannot starve the watchdog. Only complete valid lines refresh the 400 ms timeout.
CRLF, whitespace and plus signs are not accepted. USB Serial at 115200 prints `[BOOT]`, `[RX]`, `[REJECT]` and `[FAILSAFE]`. Routine command/rejection snapshots are throttled to 250 ms, with an immediate command log on startup/resumption; timeout transitions are printed once. No blocking loop delays are used.

Example packets (each ends in a single newline):

```text
120,120
255,255
-100,-100
180,80
-255,255
0,0
```

Positive means forward, negative reverse and zero stop, in the exact accepted range -255..255. The first value controls Motor A / left; the second controls Motor B / right.

The ESP32 currently mixes the **right stick**, not the left stick named in the session description: negative RY is forward, positive RX turns right, and a 50-count deadzone precedes proportional mixing. It sends every 50 ms, sends stop on detected disconnect/unusable input, and stops stale input after 300 ms at the next timer tick. The Mega independently stops after 400 ms without a complete valid command. These are implemented behaviors; the successful drive does not establish that every fault case was physically tested.

For the untethered drive, a USB power bank supplied portable control power and the separate 4.5 V pack supplied VM. Connect Mega 5 V to VCC and all grounds together. Missing VM power prevented movement during bring-up. The failed 9 V/Mega-regulator and shared motor-supply attempts are recorded in the [power debugging notes](../../README.md#power-debugging-a-small-power-bank-big-moment); the power bank is temporary.

Keep the wheels raised for the first test. From the repository root:

```bash
pio run -e mega2560
pio run -e mega2560 -t upload --upload-port /dev/ttyACM0
pio device monitor -e mega2560 --port /dev/ttyACM0 --baud 115200
```

Substitute the Mega USB port reported by `pio device list`. Close the monitor
before uploading; Ctrl+C exits. USB Serial is debug only; commands use Serial1.
See the [ESP32 instructions](../esp32_xbox_controller/README.md#experiment-003-uart-motor-control).

Bench checks: confirm startup stop, right-stick forward/reverse/turning, then
controller disconnect and ESP32/UART power loss. Both motors must stop on input
loss. Compilation alone does not verify physical wiring or motor operation.

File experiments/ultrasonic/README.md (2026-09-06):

# Ultrasonic experiments

## exp001: three sensors and traffic-light LEDs

This earlier experiment remains available; the root Mega 2560 build currently selects motor exp003. Its pins overlap motor-driver wiring, so disconnect that wiring before restoring this experiment. It measures three HC-SR04 sensors sequentially, finds the minimum distance, and lights one LED:

| Minimum distance | LED |
| --- | --- |
| <= 10 cm | RED |
| > 10 cm and <= 20 cm | YELLOW |
| > 20 cm | GREEN |

All three LEDs start LOW during setup. Each loop measures left, front, then right before updating the LEDs. The experiment does not print serial output.

## Pin assignments

| Sensor | TRIG | ECHO |
| --- | --- | --- |
| left | 22 | 23 |
| front | 24 | 25 |
| right | 26 | 27 |

| LED | Output pin |
| --- | --- |
| RED | 28 |
| YELLOW | 29 |
| GREEN | 30 |

These are the digital pin assignments in `exp001.cpp`; the LED logic uses HIGH for on and LOW for off.

## Files and responsibilities

```text
include/UltrasonicSensor.h        Class declaration
src/UltrasonicSensor.cpp          Sensor setup and measurement
src/main.cpp                     Arduino setup()/loop() launcher
experiments/ultrasonic/exp001.h   Experiment function declarations
experiments/ultrasonic/exp001.cpp Sensor objects, comparison and LEDs
platformio.ini                   Explicit build source selection
```

The experiment creates its sensors with:

```cpp
UltrasonicSensor left(TRIG1, ECHO1);
UltrasonicSensor front(TRIG2, ECHO2);
UltrasonicSensor right(TRIG3, ECHO3);
```

The constructor stores the two pins without accessing hardware. Each object has its own private `trigPin` and `echoPin` members, so the same methods operate on different pins for each sensor.

`begin()` configures TRIG as OUTPUT and ECHO as INPUT, then sets TRIG LOW. The experiment calls it once on each object during setup.

`measureDistance()` holds TRIG LOW for 2 microseconds, HIGH for 10 microseconds, then LOW again. It measures the ECHO HIGH pulse using `pulseIn()` with its default timeout and returns `pulse / 58` as a float. This preserves the original integer division: fractional centimeters are discarded before conversion to float. Measurement is blocking. A zero pulse result produces 0 cm and therefore selects RED when included in the minimum; there is no separate invalid-reading handling yet.

The sensor class only handles the sensor. The experiment owns the objects and keeps the minimum-distance calculation, thresholds, and all LED control.

## Launcher and build

To select this experiment, configure `src/main.cpp` to include `exp001.h` and call `ultrasonicExperimentSetup()` from Arduino `setup()` and `ultrasonicExperimentLoop()` from Arduino `loop()`. The experiment does not define Arduino entry points or require including a `.cpp` file.

The root `platformio.ini` sets `src_dir = .`. To restore this experiment, use this source filter (the current filter selects motor exp003):

```ini
build_src_filter =
    +<src/main.cpp>
    +<src/UltrasonicSensor.cpp>
    +<experiments/ultrasonic/exp001.cpp>
```

Run from the repository root:

```sh
pio run -e mega2560
```

The refactor passed this build with 2,348 bytes of flash and 21 bytes of RAM used. No upload was performed during the refactor; this result verifies compilation and linking, not hardware behavior after the refactor.

With that selection, other experiments remain excluded. To change the active experiment, update the launcher header/calls and source filter as described in the [root README](../../README.md#running-experiments). Keep one root project and the existing Mega environment.

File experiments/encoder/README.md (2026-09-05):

# Encoder experiments

Reserved for isolated encoder investigations. No experiment is implemented yet.

Record confirmed hardware, wiring, dependencies, procedure and observations before adding code. This directory is not selected by the current build. When an experiment is ready, keep its implementation and header here, call its setup/loop functions from `src/main.cpp`, and select its source files in the root `platformio.ini` using `build_src_filter`. Only `src/main.cpp` should define Arduino `setup()` and `loop()`. Use the existing `mega2560` environment; see the [launcher instructions](../../README.md#running-experiments).

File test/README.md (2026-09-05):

# Tests

Reserved for PlatformIO tests. No automated tests are implemented yet. Initial validation passed: the Mega firmware builds, AVRDUDE wrote and verified all 1,856 bytes, and the expected startup message was received after reset at 115200 baud. These were build and manual hardware checks, not automated tests. Add meaningful tests as subsystem behaviour is defined.

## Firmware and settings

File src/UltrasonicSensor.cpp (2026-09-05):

#include <Arduino.h>
#include "UltrasonicSensor.h"

UltrasonicSensor::UltrasonicSensor(int trigPin, int echoPin)
    : trigPin(trigPin), echoPin(echoPin)
{
}

void UltrasonicSensor::begin()
{
    pinMode(trigPin, OUTPUT);
    pinMode(echoPin, INPUT);
    digitalWrite(trigPin, LOW);
}

float UltrasonicSensor::measureDistance()
{
    digitalWrite(trigPin, LOW);
    delayMicroseconds(2);
    digitalWrite(trigPin, HIGH);
    delayMicroseconds(10);
    digitalWrite(trigPin, LOW);
    const unsigned long pulse = pulseIn(echoPin, HIGH);
    // Preserve the experiment's whole-centimeter conversion.
    const float cm = pulse / 58;
    return cm;
}

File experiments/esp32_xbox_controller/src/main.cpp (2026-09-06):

#include <cstdio>
#include <cstdint>
#include <initializer_list>

extern "C" {
#include <btstack_port_esp32.h>
#include <btstack_run_loop.h>
#include <driver/gpio.h>
#include <uni.h>
#include <uni_version.h>
#include <bt/uni_bt_allowlist.h>
}

namespace {
constexpr gpio_num_t kRed = GPIO_NUM_25;
constexpr gpio_num_t kYellow = GPIO_NUM_26;
constexpr gpio_num_t kGreen = GPIO_NUM_27;
// Leave empty for normal discovery. Optional: copy the printed address here.
// This uses Bluepad32's actual persistent allowlist, not a discovery-only filter.
constexpr char kAllowedControllerAddress[] = "";
constexpr bool kForgetPairingKeysOnBoot = false;  // Temporary recovery only.
uni_hid_device_t* active = nullptr;
uni_gamepad_t latest = {};
bool inputPending = false;
bool firstInput = true;
btstack_timer_source_t statusTimer = {};
unsigned waitingTicks = 0;

void setLeds(uint16_t buttons) {
    const bool all = buttons & BUTTON_Y;
    gpio_set_level(kRed, all || (buttons & BUTTON_B));
    gpio_set_level(kYellow, all || (buttons & BUTTON_X));
    gpio_set_level(kGreen, all || (buttons & BUTTON_A));
}

void statusTick(btstack_timer_source_t* timer) {
    if (active && inputPending) {
        const auto& g = latest;
        printf("[INPUT] A=%d B=%d X=%d Y=%d D-pad=0x%02x(U=%d D=%d L=%d R=%d) "
               "LX=%ld LY=%ld RX=%ld RY=%ld LT=%ld RT=%ld\n",
               !!(g.buttons & BUTTON_A), !!(g.buttons & BUTTON_B),
               !!(g.buttons & BUTTON_X), !!(g.buttons & BUTTON_Y),
               g.dpad, !!(g.dpad & DPAD_UP), !!(g.dpad & DPAD_DOWN),
               !!(g.dpad & DPAD_LEFT), !!(g.dpad & DPAD_RIGHT),
               static_cast<long>(g.axis_x), static_cast<long>(g.axis_y),
               static_cast<long>(g.axis_rx), static_cast<long>(g.axis_ry),
               static_cast<long>(g.brake), static_cast<long>(g.throttle));
        inputPending = false;
    }
    if (!active && ++waitingTicks >= 50) {
        printf("[WAITING] Waiting for controller; enable Xbox pairing mode.\n");
        waitingTicks = 0;
    }
    btstack_run_loop_set_timer(timer, 100);
    btstack_run_loop_add_timer(timer);
}

void onInit(int, const char**) {
    printf("[BLUEPAD32] Initializing version %s\n", UNI_VERSION_STRING);
}

void onInitComplete() {
    printf("[BLUEPAD32] Initialized; Bluetooth stack ready.\n");
    if (kAllowedControllerAddress[0]) {
        bd_addr_t addr = {};
        const bd_addr_t zero = {};
        // Fail closed on a typo: no scanning or incoming connections.
        if (!sscanf_bd_addr(kAllowedControllerAddress, addr) || bd_addr_cmp(addr, zero) == 0) {
            printf("[ERROR] Invalid allowed controller address; Bluetooth acceptance disabled.\n");
            uni_bt_allow_incoming_connections(false);
            return;
        }
        uni_bt_allowlist_remove_all();
        if (!uni_bt_allowlist_add_addr(addr)) {
            printf("[ERROR] Cannot add controller to allowlist; acceptance disabled.\n");
            uni_bt_allow_incoming_connections(false);
            return;
        }
        uni_bt_allowlist_set_enabled(true);
        printf("[IDENTITY] Only accepting Bluetooth address %s\n", bd_addr_to_str(addr));
    } else {
        // Disable any allowlist left in NVS by a previous experiment build.
        uni_bt_allowlist_set_enabled(false);
        printf("[IDENTITY] Address filtering disabled; normal discovery/pairing.\n");
    }
    if (kForgetPairingKeysOnBoot)
        uni_bt_del_keys_unsafe();
    uni_bt_allow_incoming_connections(true);
    uni_bt_start_scanning_and_autoconnect_unsafe();
    printf("[WAITING] Waiting for controller.\n");
    btstack_run_loop_set_timer_handler(&statusTimer, statusTick);
    btstack_run_loop_set_timer(&statusTimer, 100);
    btstack_run_loop_add_timer(&statusTimer);
}

uni_error_t onDiscovered(bd_addr_t addr, const char* name, uint16_t cod, uint8_t rssi) {
    printf("[DISCOVERED] Bluetooth address=%s name=%s CoD=0x%04x RSSI(raw)=%u\n",
           bd_addr_to_str(addr), name && name[0] ? name : "(not supplied)", cod, rssi);
    return UNI_ERROR_SUCCESS;
}

void onConnected(uni_hid_device_t* d) {
    printf("[CONNECTED] Controller Bluetooth address=%s; preparing HID.\n", bd_addr_to_str(d->conn.btaddr));
}

uni_error_t onReady(uni_hid_device_t* d) {
    // Report klass is not initialized until the first Xbox input report.
    if (!uni_hid_device_is_gamepad(d) || (active && active != d)) {
        printf("[REJECTED] Non-gamepad or another controller already active: %s\n", bd_addr_to_str(d->conn.btaddr));
        return UNI_ERROR_IGNORE_DEVICE;
    }
    active = d;
    firstInput = true;
    inputPending = false;
    setLeds(0);
    printf("[READY] Active controller Bluetooth address=%s; waiting for input.\n", bd_addr_to_str(d->conn.btaddr));
    return UNI_ERROR_SUCCESS;
}

void onDisconnected(uni_hid_device_t* d) {
    printf("[DISCONNECTED] Controller Bluetooth address=%s\n", bd_addr_to_str(d->conn.btaddr));
    if (active == d) {
        active = nullptr;
        inputPending = false;
        setLeds(0);
        printf("[WAITING] LEDs off; waiting for controller.\n");
    }
}

void onData(uni_hid_device_t* d, uni_controller_t* ctl) {
    if (d != active || ctl->klass != UNI_CONTROLLER_CLASS_GAMEPAD)
        return;
    // Apply every report immediately; serial snapshots are limited to 10 Hz.
    setLeds(ctl->gamepad.buttons);
    const auto& g = ctl->gamepad;
    if (firstInput || g.buttons != latest.buttons || g.dpad != latest.dpad) {
        printf("[BUTTONS] A=%d B=%d X=%d Y=%d D-pad=0x%02x\n",
               !!(g.buttons & BUTTON_A), !!(g.buttons & BUTTON_B),
               !!(g.buttons & BUTTON_X), !!(g.buttons & BUTTON_Y), g.dpad);
    }
    latest = ctl->gamepad;
    inputPending = true;
    if (firstInput) {
        printf("[INPUT] First controller input received.\n");
        firstInput = false;
    }
}

const uni_property_t* getProperty(uni_property_idx_t) { return nullptr; }
void onOob(uni_platform_oob_event_t, void*) {}
}  // namespace

extern "C" void app_main() {
    setvbuf(stdout, nullptr, _IOLBF, 0);
    printf("[BOOT] ESP32 booted: Xbox controller / traffic-light experiment, UART 115200.\n");
    for (auto pin : {kRed, kYellow, kGreen}) {
        gpio_reset_pin(pin);
        gpio_set_direction(pin, GPIO_MODE_OUTPUT);
    }
    setLeds(0);
    static uni_platform platform = {};
    platform.name = "wittle_xbox_experiment";
    platform.init = onInit;
    platform.on_init_complete = onInitComplete;
    platform.on_device_discovered = onDiscovered;
    platform.on_device_connected = onConnected;
    platform.on_device_disconnected = onDisconnected;
    platform.on_device_ready = onReady;
    platform.on_controller_data = onData;
    platform.get_property = getProperty;
    platform.on_oob_event = onOob;
    btstack_init();
    uni_platform_set_custom(&platform);
    uni_init(0, nullptr);
    // Event-driven BTstack loop dispatches input and timers; no delay() calls.
    btstack_run_loop_execute();
}

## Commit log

2026-09-05 Added initial Wittle firmware architecture 😉
2026-09-05 built and refactored ultrasonic experiment .. this is starting to look promising 🤣
2026-09-05 assembled wittle's body hehe ..
2026-09-06 experimented on remote control with an xbox gamepad ... it will be useful later.. 😉
    [partitions.csv]
2026-09-06 Wittle takes his first wireless steps 🤖🎮 ..
2026-09-07 it was a well spend evening on blender lol ... first body parts are on the line 🤣
    [001_body_v0.1.stl, 002_body_v0.1_key.stl, 003_traffic_light_holder.stl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]
2026-09-09 rearranged blender's folder + found some cool parts online for v002 ... having some technicalities with my ender 3 3Dprinter ... still sorting that out ... for now thats the game .. 😉
    [001_body_v0.1.stl, 001_body_v1.stl, 002_body_key_v01.stl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]
2026-09-10 solved the technicalities with the printer (for now .. 🤣) and got down to assembling the power bus ... more parts coming out soon ... for now that all! 😉
    [004_Bp_clamp.stl, 005_Bp_spine.stl, 005_clip.stl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]
2026-09-10 removed gCode from the equation ... it's too heavy and provides no value whatsoever to the repo ... 😉
